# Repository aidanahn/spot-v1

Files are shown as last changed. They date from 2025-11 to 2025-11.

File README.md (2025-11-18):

# spot-v1

## Table of Contents
1. [Description](#description)
2. [Milo](#milo-wip)
3. [Tools](#tools)
4. [Bill of Materials](#bill-of-materials)
5. [Fastener List](#fastener-list)
6. [Printing List](#printing-list)
7. [Printing Orientations](#printing-orientations)
8. [License](#license)

## Description
A fast and reliable 4WD 3D-printable RC car design

Assembly: [Onshape Link](https://cad.onshape.com/documents/7f341d22941a2e14df29ce4a/w/e412618fee4bd938372718a9/e/cd4b9ad8284ddeb69a4dfc13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)

## Milo (WIP)
Track & Field pacer designed to run consistent lap times and help with pacing during training (Uses the same car design from Spot V1).

Check the project out here: (https://github.com/aidanahn/pacer_v3_control)

## Tools
- 3D Printer
- Hacksaw
- Allen Keys
  - 2.0mm
  - 2.5mm
  - 3.0mm

## Bill of Materials
| Quantity | Part Name | Specifications |
| --- | --- | --- |
| 19 | 10x15x4mm Bearing | |
| 4 | 5x10x4mm Bearing | |
| 1 | 8x12x3.5mm Bearing | |
| 2 | 200mm M3 Rod | |
| 4 | M3 Tie Rod End | |
| 1 | 35kg Servo | |
| 1 | Motor | Motor mount built for [QUICRUN Fusion SE (2in1 FOC system)](https://www.hobbywingdirect.com/collections/quicrun-brushless-system/products/quicrun-fusion-se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) |
| 1 | RC Reciever | |
| 1 | ESC | |
| 4 | Wheels | Wheel Hub built for 14mm hex wheels |
| 1 | LiPo Battery | |
| 1 | 20T Timing Pulley | Must have 8mm bore |
| 1 | 40T Timing Pulley | Must have 8mm bore |
| 1 | 120mm Timing Belt | |
| 2 | Differential | The differential case is specifically built to house [this differential](https://www.amazon.com/Mirthobby-Housing-Complete-Volcano-Unassembled/dp/B07YWQ7G9Q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) |
| | PETG Filament | |
| | Grease | |

## Fastener List
| Quantity | Size | Length | Head | Type |
| --- | ---- | --- | ---- | ---- |
| 16 | M3 | 16mm | Socket Head | Screw |
| 18 | M3 | 12mm | Socket Head | Screw |
| 14 | M3 | 12mm | Button Head | Screw |
| 2 | M3 | 20mm | Socket Head | Screw |
| 15 | M3 | 25mm | Socket Head | Screw |
| 8 | M3 | 35mm | Socket Head | Screw |
| 6 | M3 | | | Washer |
| 16 | M3 | 4mm | Socket Head | Screw |
| 13 | M3 | | | Nut |
| 4 | M3 | 8mm | Button Head | Screw |
| 4 | M3 | 16mm | Button Head | Screw |
| 1 | M3 | 30mm | Socket Head | Screw |
| 4 | M4 | 20mm | Socket Head | Screw |
| 4 | M4 | | | Nylon Locknut |

## Printing List
| Quantity | Part Name | Description |
| --- | --- | --- |
| 1 | [Front Chassis](cad/Front_Chassis.step) | Main structural front frame holding servo, steering linkages, and front suspension system|
| 1 | [Rear Chassis](cad/Rear_Chassis.step) | Main structural rear frame holding motor, belt drive, and rear suspension system|
| 1 | [Right Reinforcement Beam](cad/Right_Reinforcement_Beam.step) | Connects front chassis to rear chassis |
| 1 | [Left Reinforcement Beam](cad/Left_Reinforcement_Beam.step) | Connects front chassis to rear chassis |
| 2 | [Lower Differential Case](cad/Lower_Differential_Case.step) | Protective housing for differential |
| 2 | [Upper Differential Case](cad/Upper_Differential_Case.step) | Protective housing for differential |
| 2 | [Upper Control Arm Bracket](cad/Upper_Control_Arm_Bracket.step) | Mounting bracket for the upper control arms to attach to the chassis |
| 4 | [Upper Control Arm](cad/Upper_Control_Arm.step) | Upper suspension arm that connects uprights to the chassis |
| 1 | [Rear Left Lower Control Arm](cad/Rear_Left_Lower_Control_Arm.step) | Lower suspension arm that connects uprights to the chassis |
| 1 | [Rear Right Lower Control Arm](cad/Rear_Right_Lower_Control_Arm.step) | Lower suspension arm that connects uprights to the chassis |
| 1 | [Front Left Lower Control Arm](cad/Front_Left_Lower_Control_Arm.step) | Lower suspension arm that connects uprights to the chassis |
| 1 | [Front Right Lower Control Arm](cad/Front_Right_Lower_Control_Arm.step) | Lower suspension arm that connects uprights to the chassis |
| 1 | [Electronics Bed](cad/Electronics_Bed.step) | Strengthens connection between front and rear chassis and acts as mounting plate for electronics (ESC, receiver, LiPo, etc) |
| 4 | [Differential Drive Cup Adapter](cad/Differential_Drive_Cup_Adapter.step) | Adapter between differential output and drive cup |
| 4 | [Differential Drive Cup](cad/Differential_Drive_Cup.step) | Cup that connects differential output to drive the wheels |
| 2 | [Front Upright](cad/Front_Upright.step) | Front wheel carrier that allows the steering knuckles to pivot and houses the wheel drive cup |
| 2 | [Rear Upright](cad/Rear_Upright.step) | Rear wheel carrier housing the wheel drive cup |
| 2 | [Pinion Carrier](cad/Pinion_Carrier.step) | Holds differential pinion gears in place |
| 1 | [Left Steering Knuckle](cad/Left_Steering_Knuckle.step) | Allows wheels to pivot for steering input |
| 1 | [Right Steering Knuckle](cad/Right_Steering_Knuckle.step) | Allows wheels to pivot for steering input |
| 1 | [Servo Mount](cad/Servo_Mount.step) | Holds servo securely in place |
| 1 | [Servo Steering Linkage](cad/Servo_Steering_Linkage.step) | Transmits servo power to the steering bar |
| 1 | [Steering Bar](cad/Steering_Bar.step) | Main steering bar linking left and right wheels |
| 1 | [Steering Linkage](cad/Steering_Linkage.step) | Follows the same motion as the steering linkage to keep the steering bar in place |
| 4 | [Wheel Drive Cup](cad/Wheel_Drive_Cup.step) | Connects wheel hubs to the differential output cups |
| 4 | [Wheel Hub](cad/Wheel_Hub.step) | Mounting point for wheels |
| 1 | [Steering Mount](cad/Steering_Mount.step) | Allows the steering linkage to pivot around its axis |
| 4 | [Dogbone](cad/Dogbone.step) | Transfers power directly from the differential drive cup to the wheel drive cup |
| 1 | [Front Gearbox Cover](cad/Front_Gearbox_Cover.step) | Covers the frontside of the belt drive system |
| 1 | [Rear Gearbox Cover](cad/Rear_Gearbox_Cover.step) | Covers the rearside of the belt drive system |
| 1 | [Front Gearbox Cup](cad/Front_Gearbox_Cup.step) | Outputs power to the front differential set |
| 1 | [Rear Gearbox Cup](cad/Rear_Gearbox_Cup.step) | Outputs power to the rear differential set |
| 1 | [Shaft Coupling](cad/Shaft_Coupling.step) | Mounts onto motor shaft to transfer power to timing pulleys |

## Printing Orientations
### Front Chassis
**Recommended Print Settings:**
- **Layer Height:** 0.2mm
- **Infill:** 15% (Gyroid)
- **Supports:** Yes (Manual)
- **Material:** PETG
- **Brim:** Outer brim only

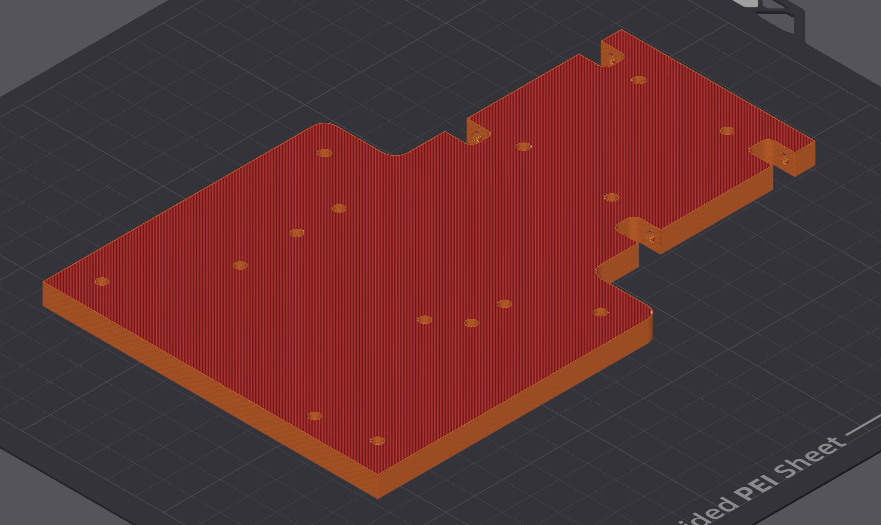
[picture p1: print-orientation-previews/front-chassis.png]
Front Chassis


### Rear Chassis
**Recommended Print Settings:**
- **Layer Height:** 0.2mm
- **Infill:** 15% (Gyroid)
- **Supports:** Yes (Manual)
- **Material:** PETG
- **Brim:** Outer brim only

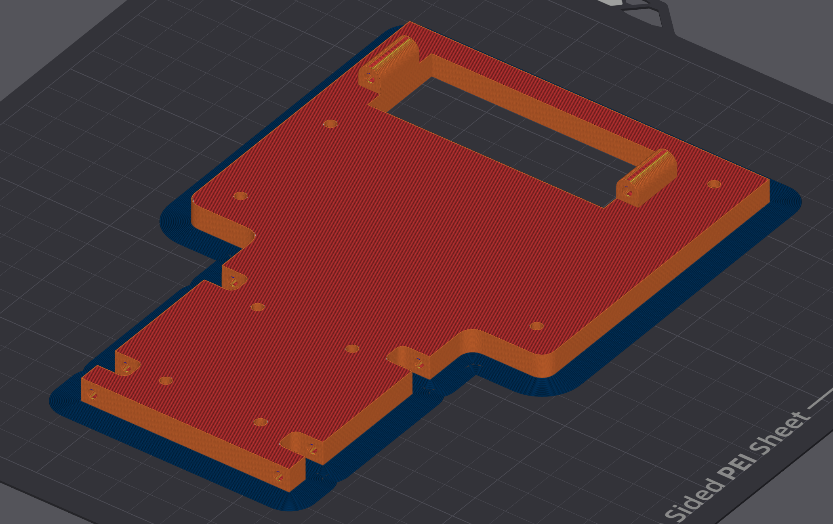
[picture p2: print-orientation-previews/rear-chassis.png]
Rear Chassis


### Right Reinforcement Beam
**Recommended Print Settings:**
- **Layer Height:** 0.2mm
- **Infill:** 15% (Gyroid)
- **Supports:** No
- **Material:** PETG
- **Brim:** Outer brim only

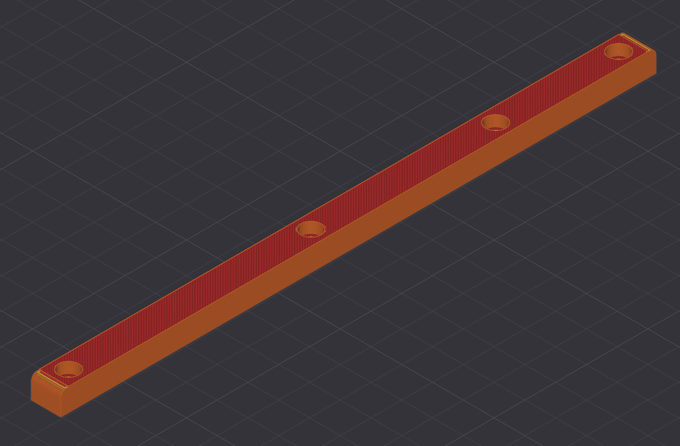
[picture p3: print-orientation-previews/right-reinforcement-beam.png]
Right Reinforcement Beam


### Left Reinforcement Beam
**Recommended Print Settings:**
- **Layer Height:** 0.2mm
- **Infill:** 15% (Gyroid)
- **Supports:** No
- **Material:** PETG
- **Brim:** Outer brim only

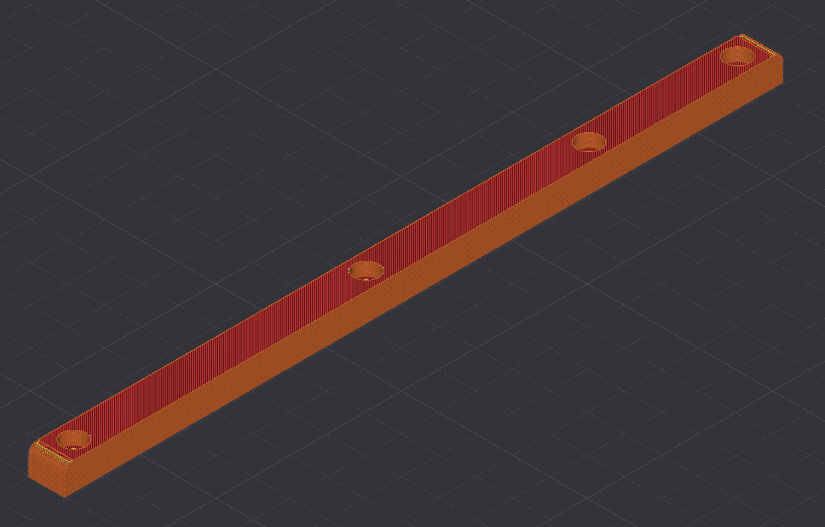
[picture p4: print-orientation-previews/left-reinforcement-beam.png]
Left Reinforcement Beam


### Lower Differential Case
**Recommended Print Settings:**
- **Layer Height:** 0.2mm
- **Infill:** 15% (Gyroid)
- **Supports:** Yes (Manual)
- **Material:** PETG
- **Brim:** Outer brim only

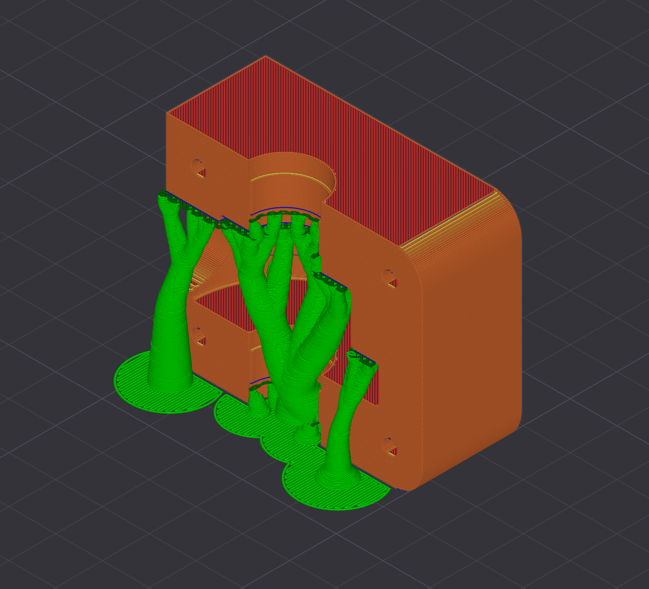
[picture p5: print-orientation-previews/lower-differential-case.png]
Lower Differential Case


### Upper Differential Case
**Recommended Print Settings:**
- **Layer Height:** 0.2mm
- **Infill:** 15% (Gyroid)
- **Supports:** Yes (Manual)
- **Material:** PETG
- **Brim:** Outer brim only

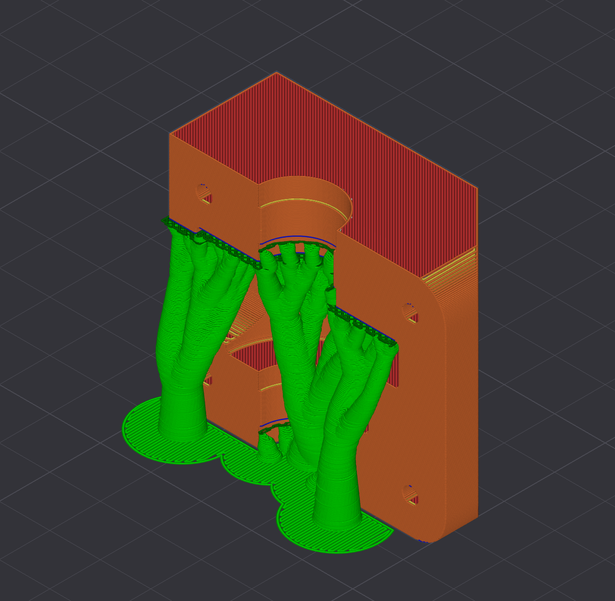
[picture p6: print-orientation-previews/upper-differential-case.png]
Upper Differential Case


### Upper Control Arm Bracket
**Recommended Print Settings:**
- **Layer Height:** 0.2mm
- **Infill:** 15% (Gyroid)
- **Supports:** No
- **Material:** PETG
- **Brim:** Outer brim only

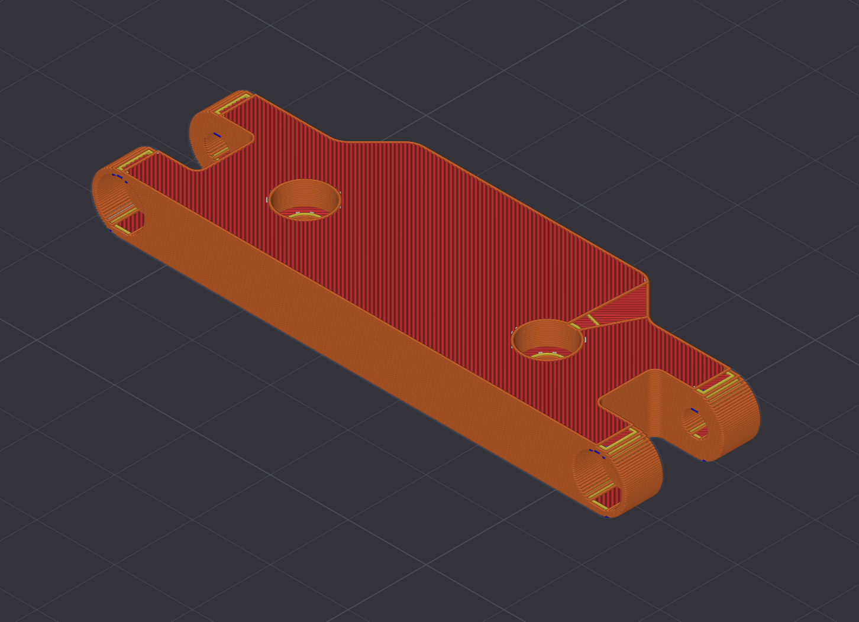
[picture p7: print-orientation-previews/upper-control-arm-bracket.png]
Upper Control Arm Bracket


### Upper Control Arm
**Recommended Print Settings:**
- **Layer Height:** 0.2mm
- **Infill:** 30% (Gyroid)
- **Supports:** No
- **Material:** PETG
- **Brim:** Outer brim only

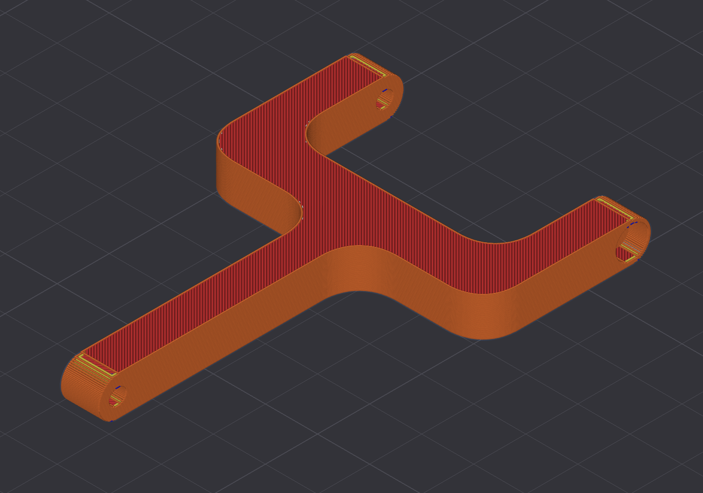
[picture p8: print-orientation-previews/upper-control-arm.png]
Upper Control Arm


### Lower Control Arm
**Recommended Print Settings:**
- **Layer Height:** 0.2mm
- **Infill:** 30% (Gyroid)
- **Supports:** No
- **Material:** PETG
- **Brim:** Outer brim only

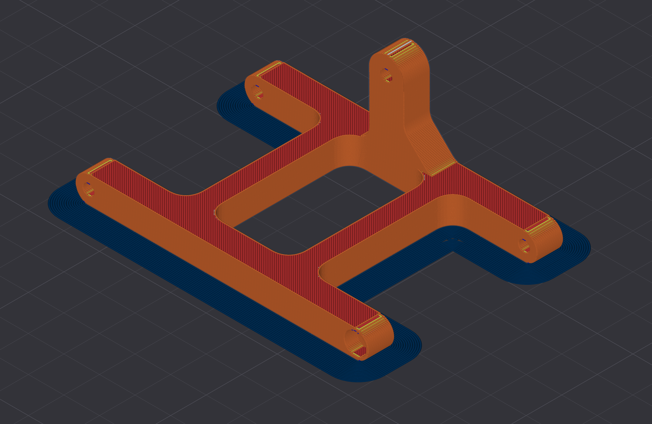
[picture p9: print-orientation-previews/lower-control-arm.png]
Lower Control Arm


### Electronics Bed
**Recommended Print Settings:**
- **Layer Height:** 0.2mm
- **Infill:** 15% (Gyroid)
- **Supports:** Yes (Automatic)
- **Material:** PETG
- **Brim:** Outer brim only

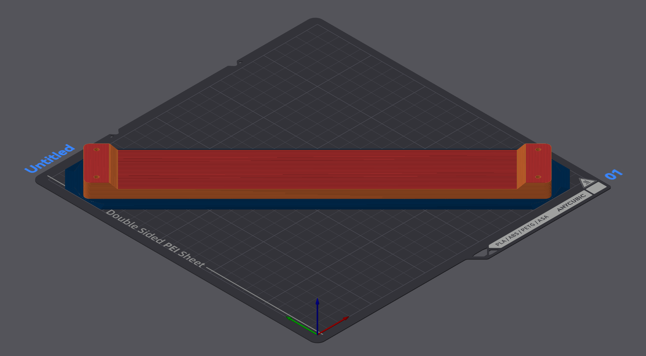
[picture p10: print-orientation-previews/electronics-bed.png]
Electronics Bed


### Differential Drive Cup Adapter
**Recommended Print Settings:**
- **Layer Height:** 0.1mm
- **Infill:** 30% (Gyroid)
- **Supports:** Yes (Automatic)
- **Material:** PETG

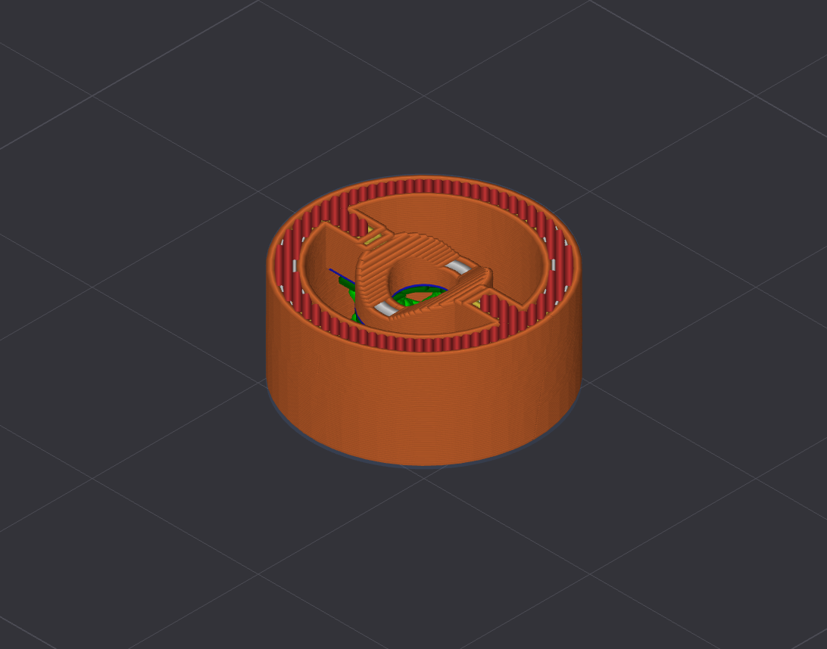
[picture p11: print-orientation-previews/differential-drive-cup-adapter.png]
Differential Drive Cup Adapter


### Differential Drive Cup
**Recommended Print Settings:**
- **Layer Height:** 0.1mm
- **Infill:** 30% (Gyroid)
- **Supports:** Yes (Automatic)
- **Material:** PETG

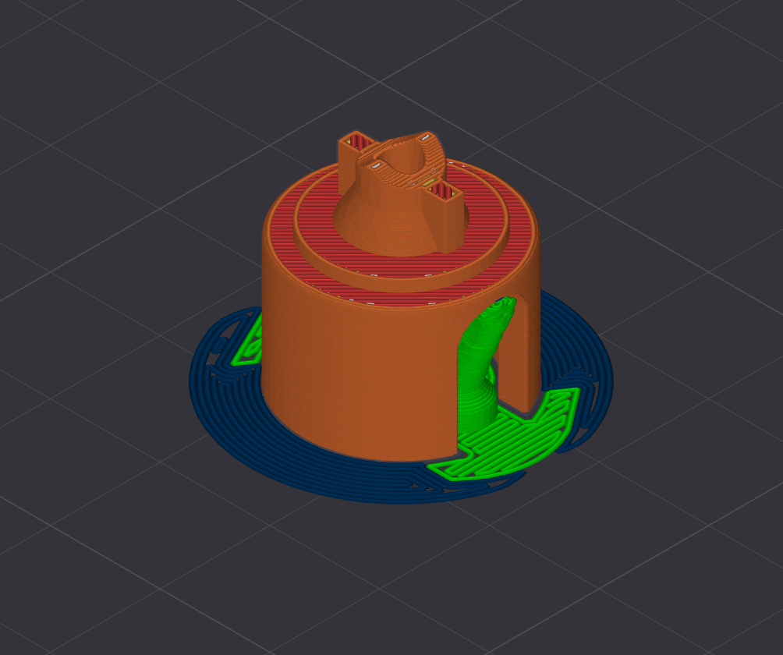
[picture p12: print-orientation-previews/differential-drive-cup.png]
Differential Drive Cup


### Front Upright
**Recommended Print Settings:**
- **Layer Height:** 0.2mm
- **Infill:** 30% (Gyroid)
- **Supports:** Yes (Manual)
- **Material:** PETG

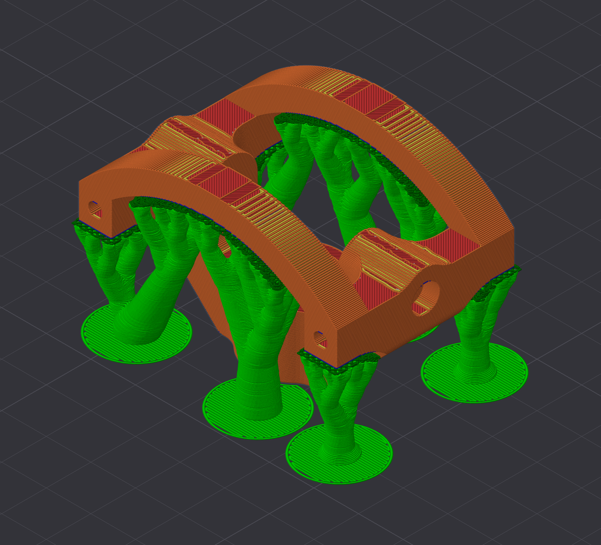
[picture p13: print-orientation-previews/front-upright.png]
Front Upright


### Rear Upright
**Recommended Print Settings:**
- **Layer Height:** 0.2mm
- **Infill:** 30% (Gyroid)
- **Supports:** Yes (Manual)
- **Material:** PETG

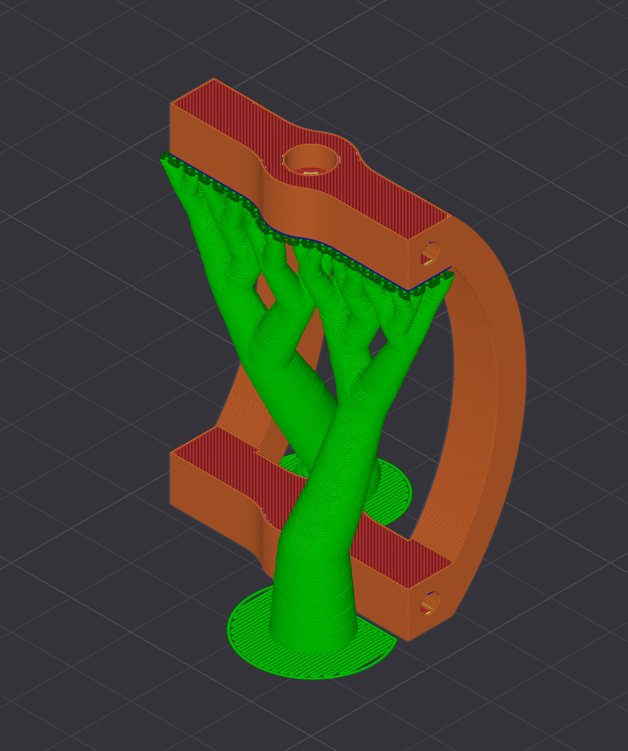
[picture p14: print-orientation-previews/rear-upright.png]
Rear Upright


### Pinion Carrier
**Recommended Print Settings:**
- **Layer Height:** 0.2mm
- **Infill:** 15% (Gyroid)
- **Supports:** No
- **Material:** PETG
- **Brim:** Outer brim only

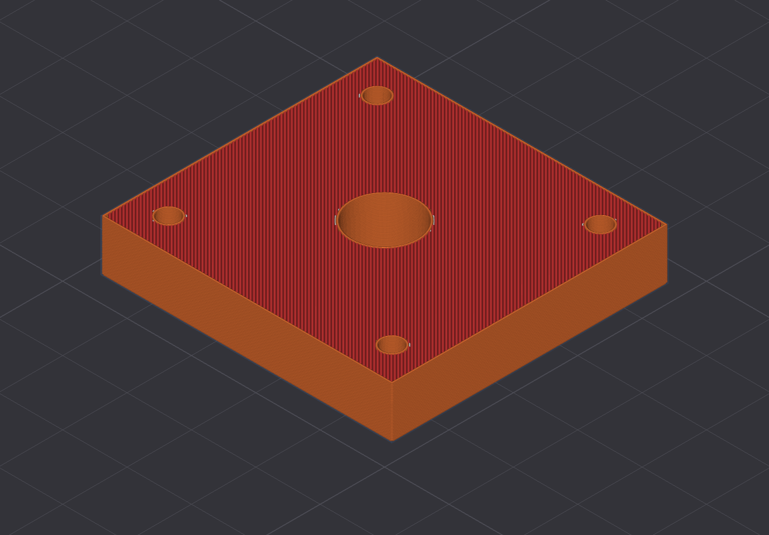
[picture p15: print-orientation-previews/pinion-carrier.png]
Pinion Carrier


### Steering Knuckle
**Recommended Print Settings:**
- **Layer Height:** 0.2mm
- **Infill:** 30% (Gyroid)
- **Supports:** Yes (Manual)
- **Material:** PETG

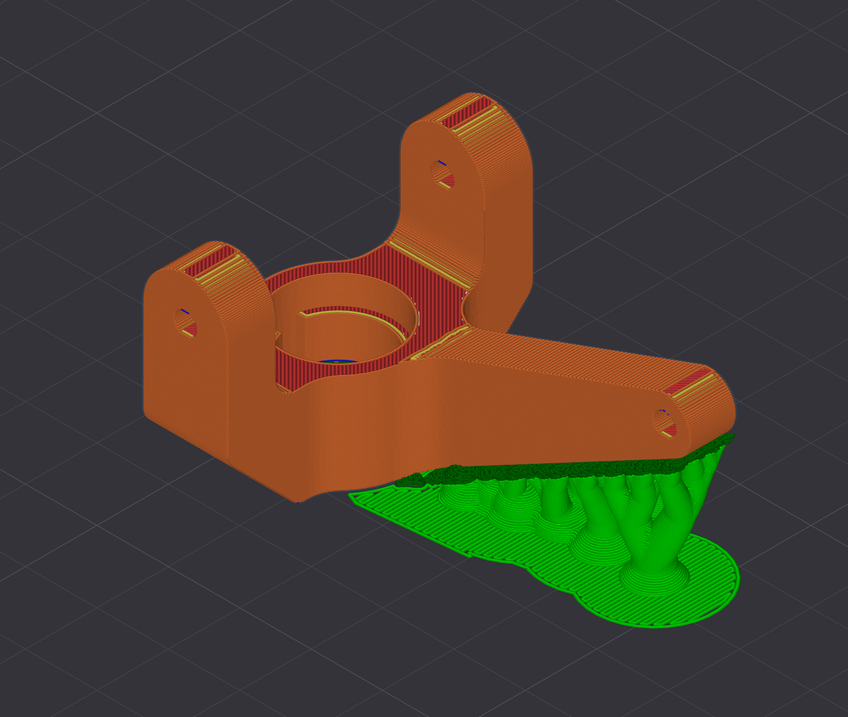
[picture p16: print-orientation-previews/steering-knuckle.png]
Steering Knuckle


### Servo Mount
**Recommended Print Settings:**
- **Layer Height:** 0.2mm
- **Infill:** 30% (Gyroid)
- **Supports:** Yes (Manual)
- **Material:** PETG

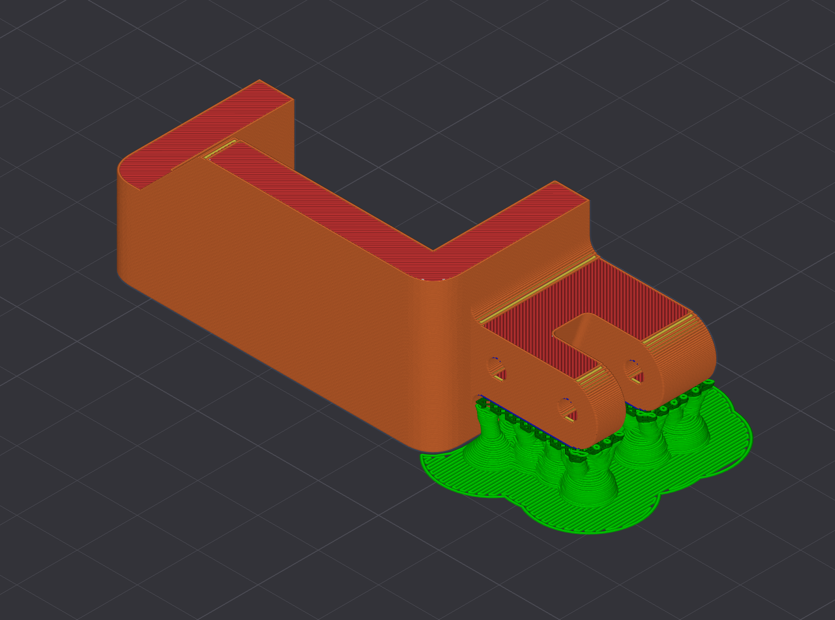
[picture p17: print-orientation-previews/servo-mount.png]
Servo Mount


### Servo Steering Linkage
**Recommended Print Settings:**
- **Layer Height:** 0.2mm
- **Infill:** 30% (Gyroid)
- **Supports:** No
- **Material:** PETG

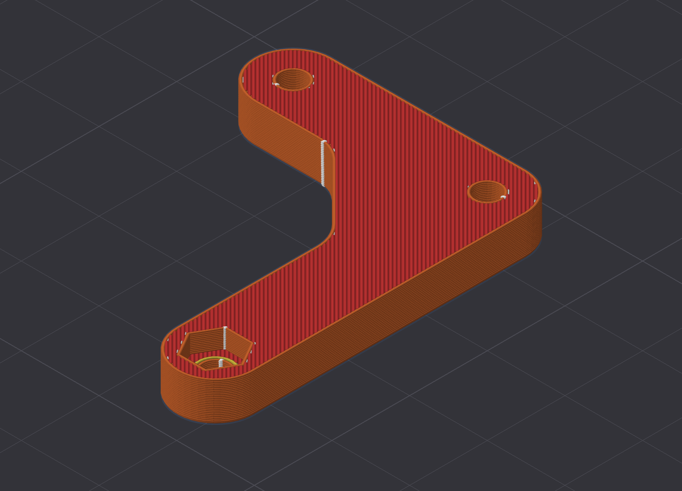
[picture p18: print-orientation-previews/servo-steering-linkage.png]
Servo Steering Linkage


### Steering Bar
**Recommended Print Settings:**
- **Layer Height:** 0.2mm
- **Infill:** 30% (Gyroid)
- **Supports:** No
- **Material:** PETG

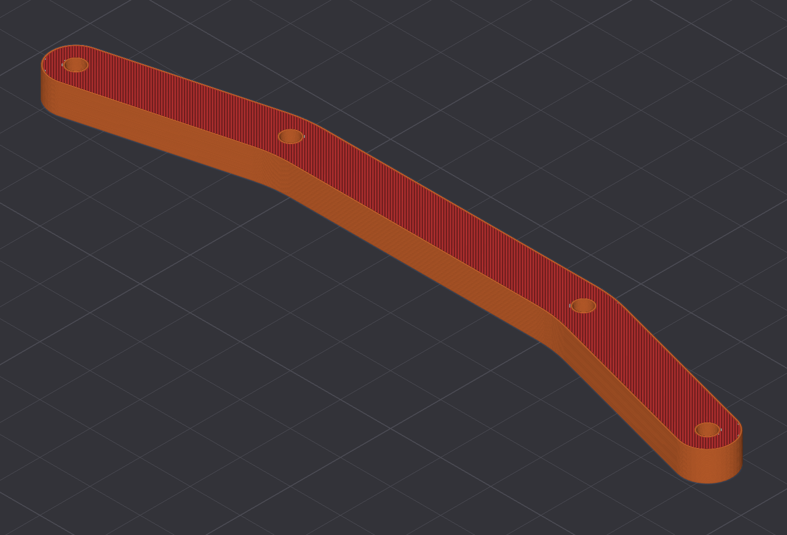
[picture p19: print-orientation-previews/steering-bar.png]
Steering Bar


### Steering Linkage
**Recommended Print Settings:**
- **Layer Height:** 0.2mm
- **Infill:** 30% (Gyroid)
- **Supports:** No
- **Material:** PETG

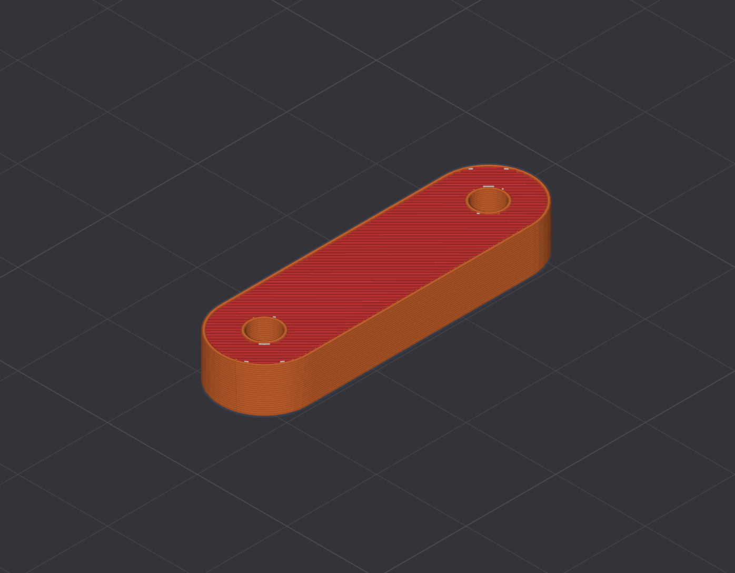
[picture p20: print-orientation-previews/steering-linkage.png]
Steering Linkage


### Wheel Drive Cup
**Recommended Print Settings:**
- **Layer Height:** 0.2mm
- **Infill:** 30% (Gyroid)
- **Supports:** Yes (Automatic)
- **Material:** PETG

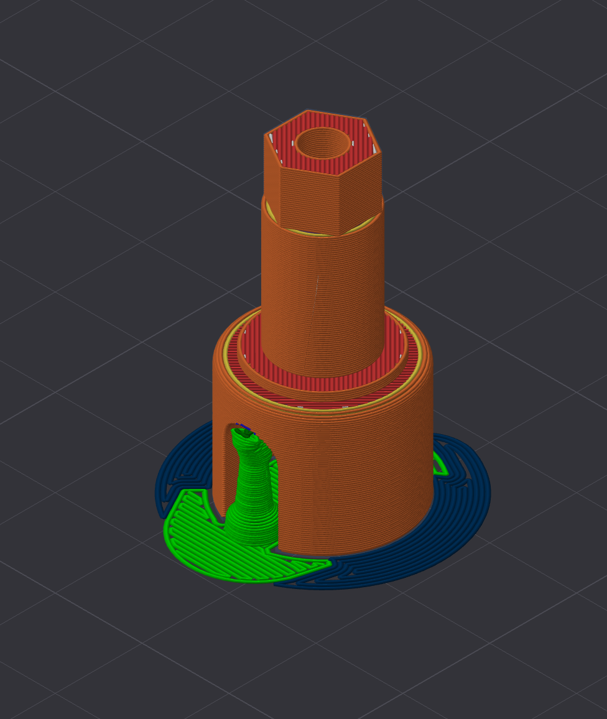
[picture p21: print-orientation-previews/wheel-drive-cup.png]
Wheel Drive Cup


### Wheel Hub
**Recommended Print Settings:**
- **Layer Height:** 0.2mm
- **Infill:** 30% (Gyroid)
- **Supports:** No
- **Material:** PETG

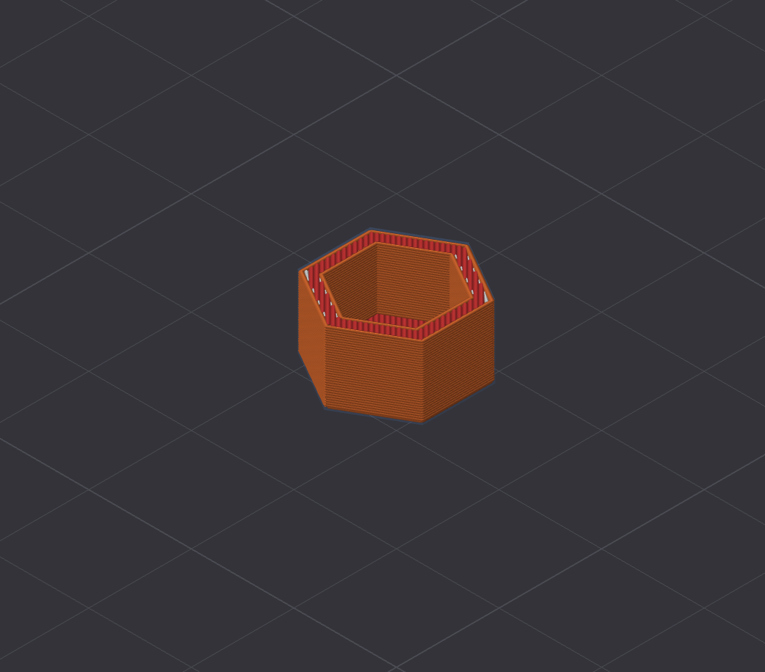
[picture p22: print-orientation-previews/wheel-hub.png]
Wheel Hub


### Steering Mount
**Recommended Print Settings:**
- **Layer Height:** 0.2mm
- **Infill:** 30% (Gyroid)
- **Supports:** No
- **Material:** PETG

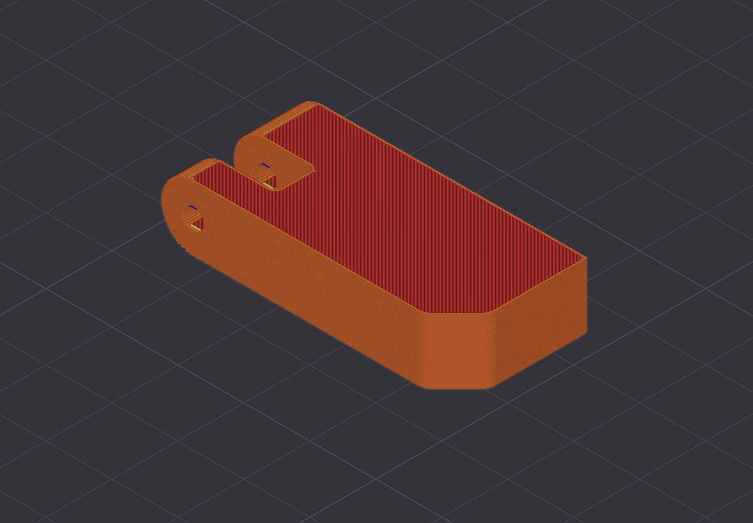
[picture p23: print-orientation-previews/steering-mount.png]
Steering Mount


### Dogbone
**Recommended Print Settings:**
- **Layer Height:** 0.1mm
- **Infill:** 30% (Gyroid)
- **Supports:** Yes (Automatic)
- **Material:** PETG

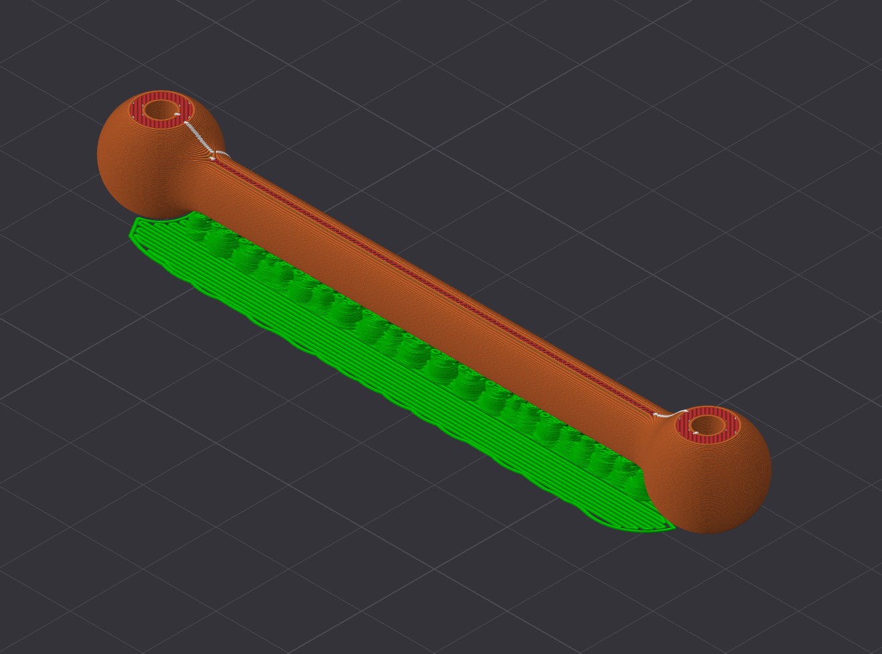
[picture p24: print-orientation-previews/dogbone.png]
Dogbone


### Front Gearbox Cover
**Recommended Print Settings:**
- **Layer Height:** 0.2mm
- **Infill:** 30% (Gyroid)
- **Supports:** Yes (Automatic)
- **Material:** PETG

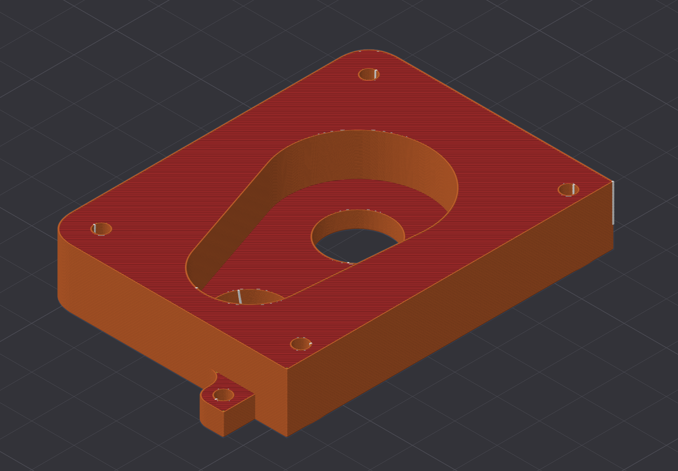
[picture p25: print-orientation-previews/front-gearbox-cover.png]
Front Gearbox Cover


### Rear Gearbox Cover
**Recommended Print Settings:**
- **Layer Height:** 0.2mm
- **Infill:** 30% (Gyroid)
- **Supports:** No
- **Material:** PETG

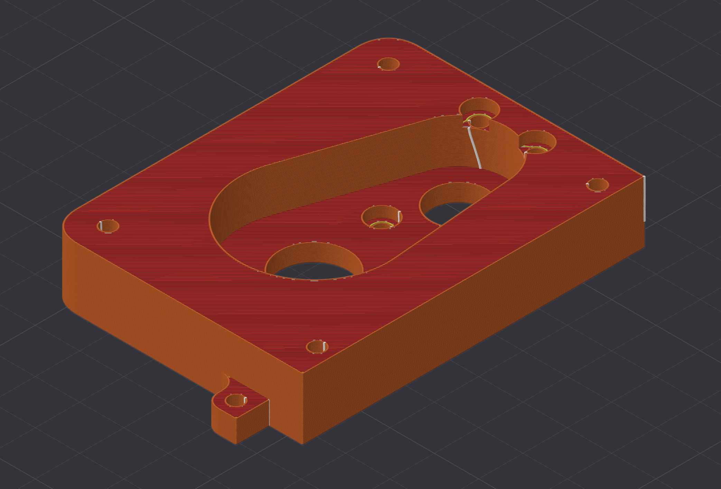
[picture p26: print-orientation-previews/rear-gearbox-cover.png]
Rear Gearbox Cover


### Front Gearbox Cup
**Recommended Print Settings:**
- **Layer Height:** 0.2mm
- **Infill:** 30% (Gyroid)
- **Supports:** Yes (Automatic)
- **Material:** PETG

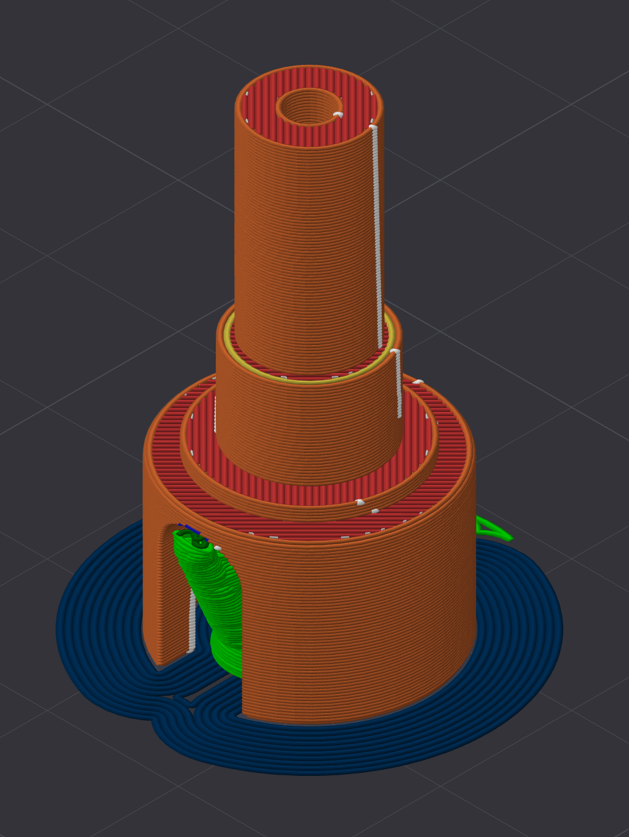
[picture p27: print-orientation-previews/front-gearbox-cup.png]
Front Gearbox Cup


### Rear Gearbox Cup
**Recommended Print Settings:**
- **Layer Height:** 0.2mm
- **Infill:** 30% (Gyroid)
- **Supports:** Yes (Automatic)
- **Material:** PETG

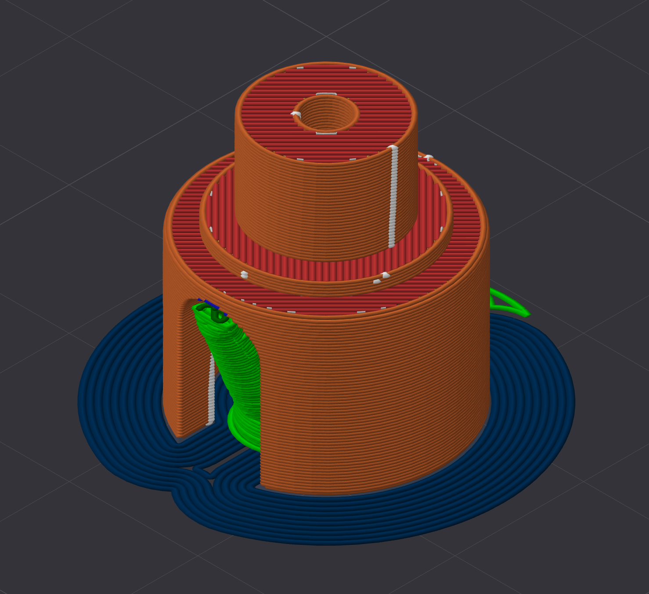
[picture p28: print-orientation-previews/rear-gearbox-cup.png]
Rear Gearbox Cup


### Shaft Coupling
**Recommended Print Settings:**
- **Layer Height:** 0.1mm
- **Infill:** 30% (Gyroid)
- **Supports:** Yes (Automatic)
- **Material:** PETG

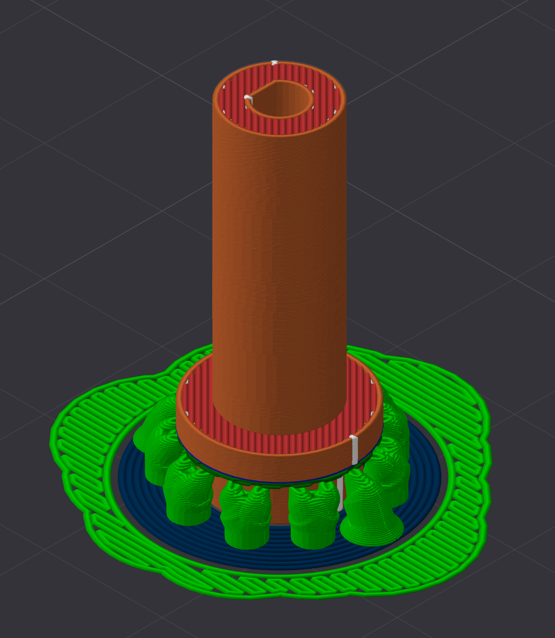
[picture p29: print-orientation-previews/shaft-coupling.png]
Shaft Coupling


## License
This work is licensed under a [MIT License](LICENSE).

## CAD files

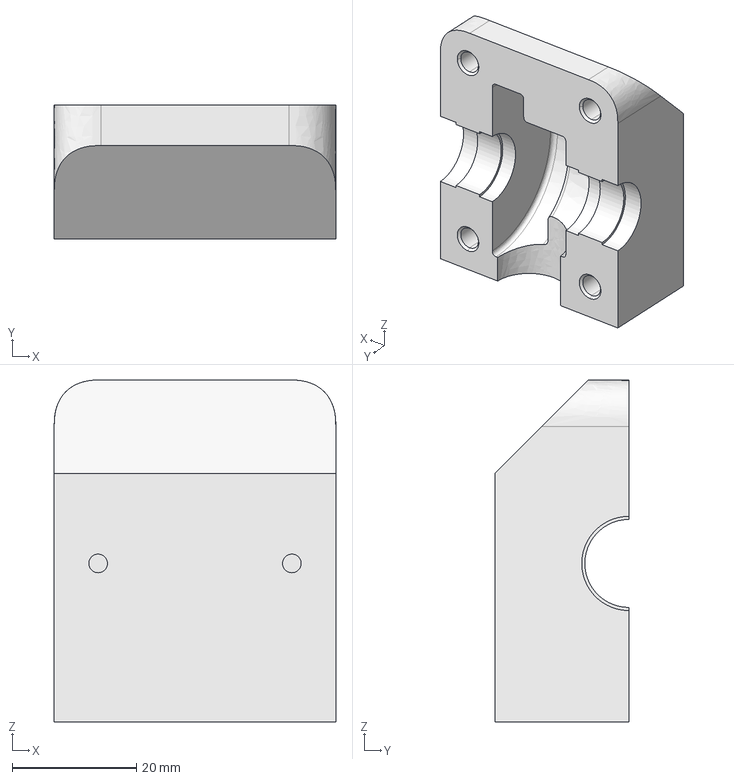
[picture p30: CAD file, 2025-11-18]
cad/Upper_Differential_Case.step
45.3 x 21.5 x 55.0 mm

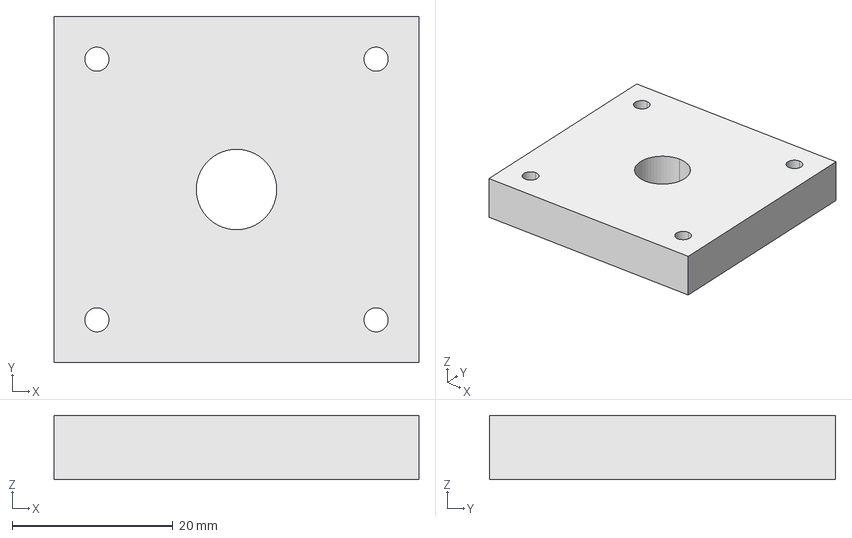
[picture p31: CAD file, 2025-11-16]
cad/Pinion_Carrier.step
45.3 x 43.0 x 8.00 mm

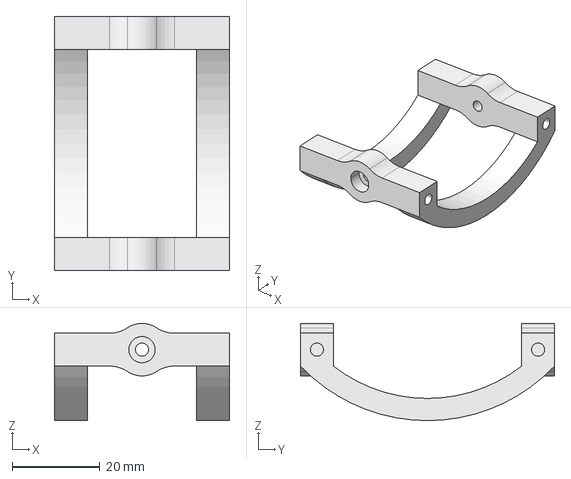
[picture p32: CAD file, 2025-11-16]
cad/Front_Upright.step
40.0 x 58.0 x 22.2 mm

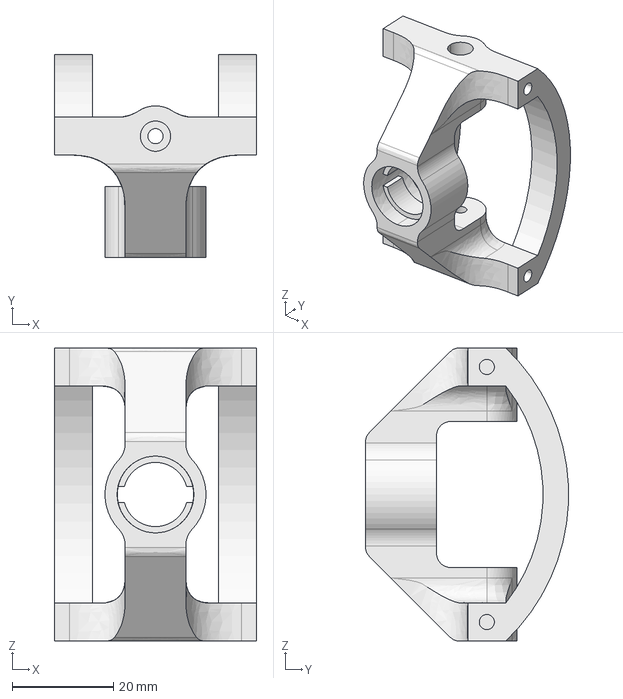
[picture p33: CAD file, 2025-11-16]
cad/Rear_Upright.step
40.0 x 40.2 x 58.0 mm

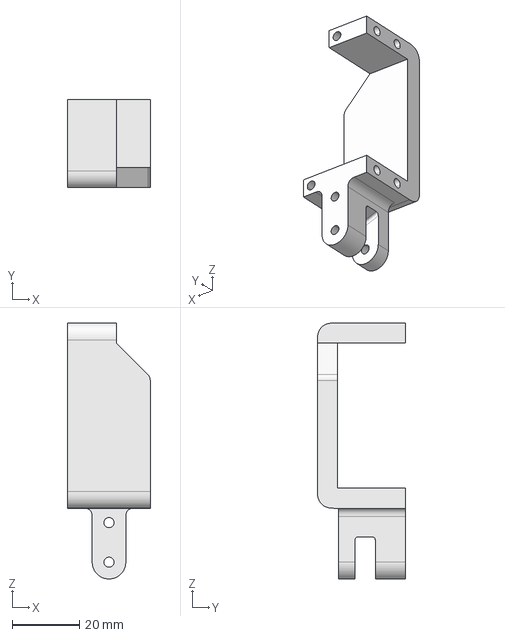
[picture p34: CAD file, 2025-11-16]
cad/Servo_Mount.step
24.5 x 26.2 x 76.0 mm

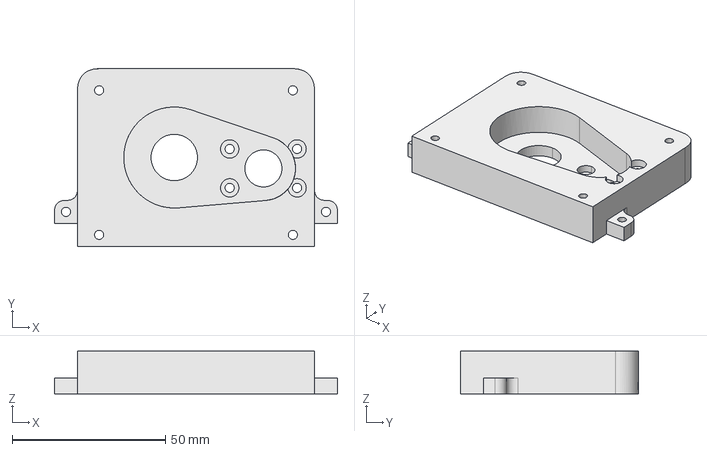
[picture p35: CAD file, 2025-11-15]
cad/Rear_Gearbox_Cover.step
92.4 x 58.0 x 14.0 mm

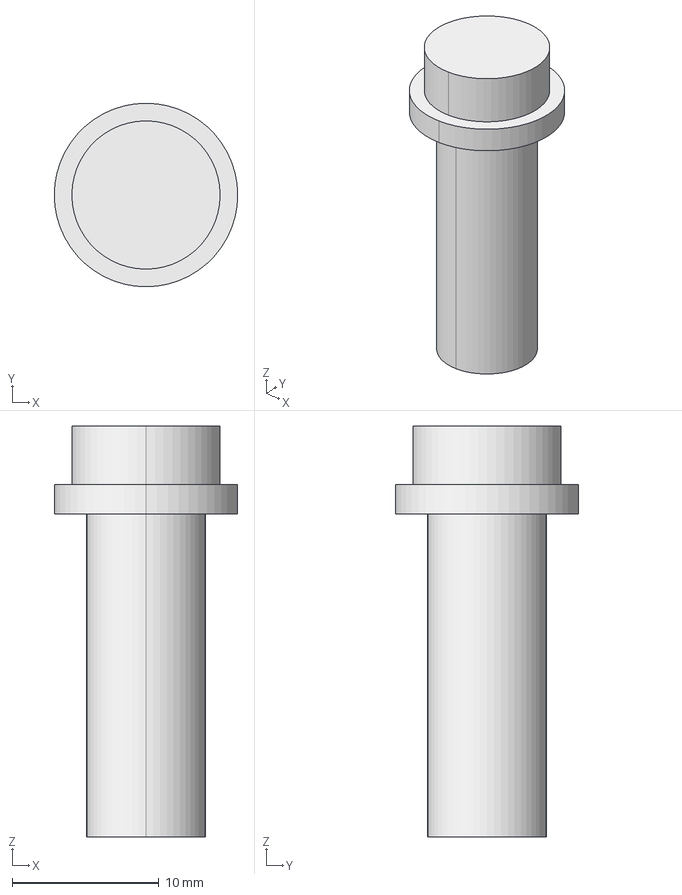
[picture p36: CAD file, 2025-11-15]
cad/Shaft_Coupling.step
12.5 x 12.5 x 28.0 mm

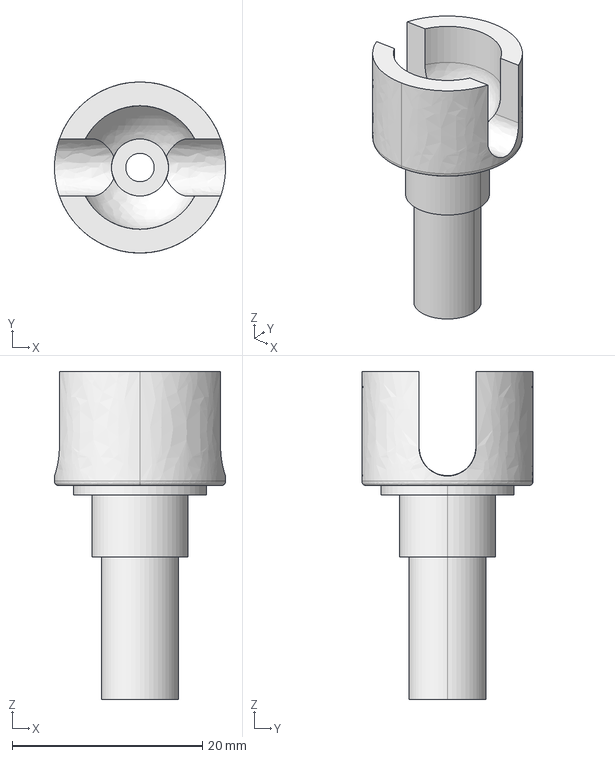
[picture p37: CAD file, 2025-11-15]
cad/Front_Gearbox_Cup.step
18.0 x 18.0 x 34.5 mm

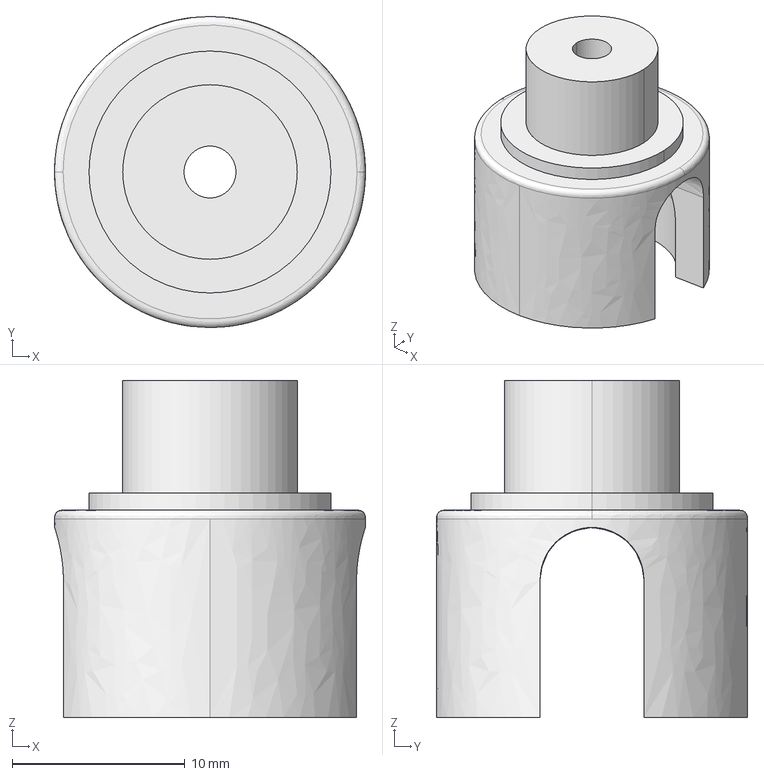
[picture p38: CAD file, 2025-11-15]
cad/Rear_Gearbox_Cup.step
18.0 x 18.0 x 19.5 mm

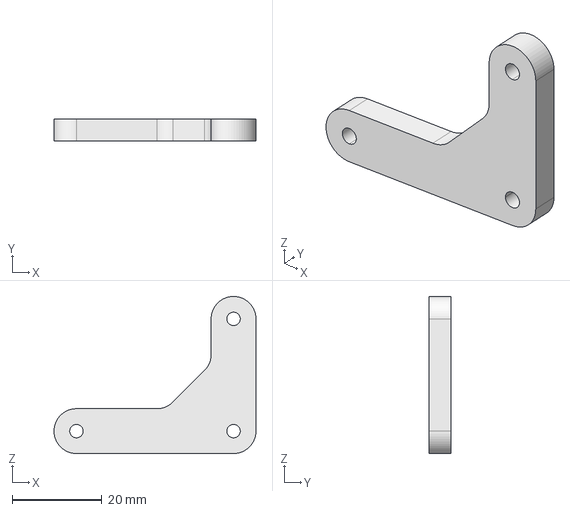
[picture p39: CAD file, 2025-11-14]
cad/Servo_Steering_Linkage.step
45.0 x 5.00 x 35.0 mm

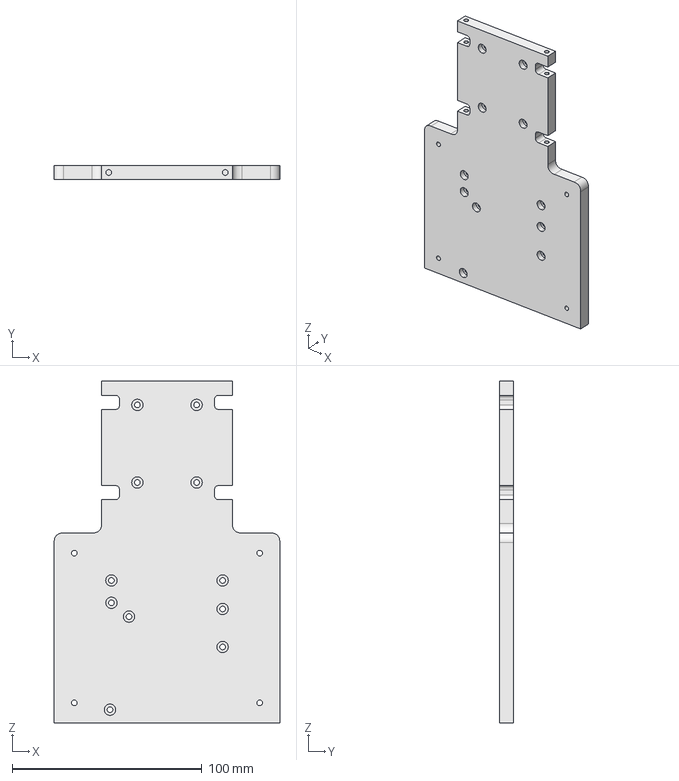
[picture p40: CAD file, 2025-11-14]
cad/Front_Chassis.step
118.8 x 7.50 x 180.0 mm

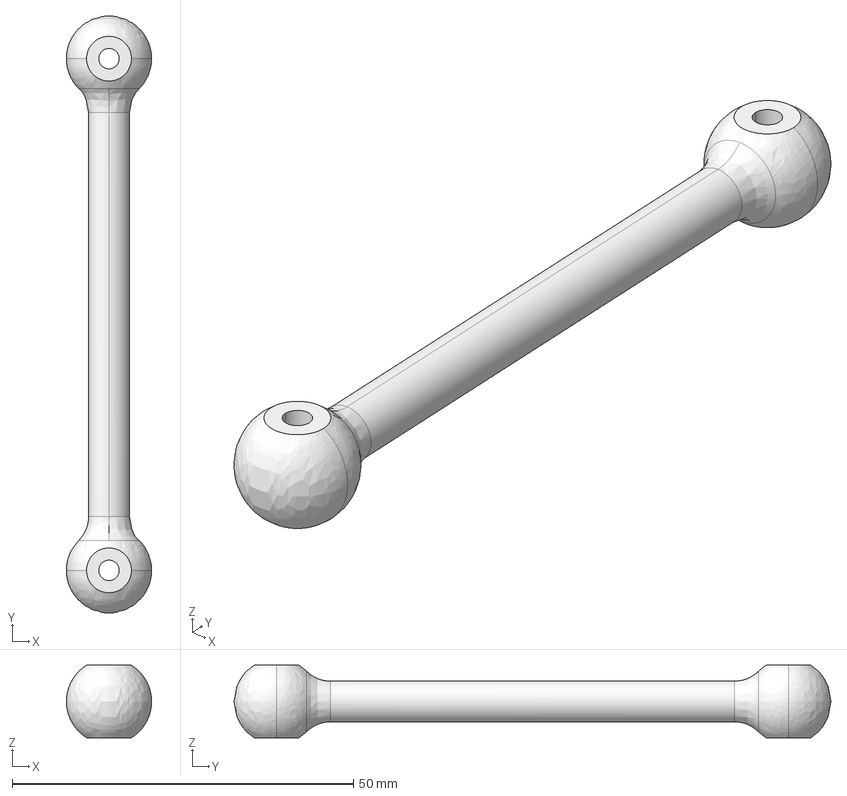
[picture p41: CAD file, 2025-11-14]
cad/Dogbone.step
12.5 x 87.5 x 10.6 mm

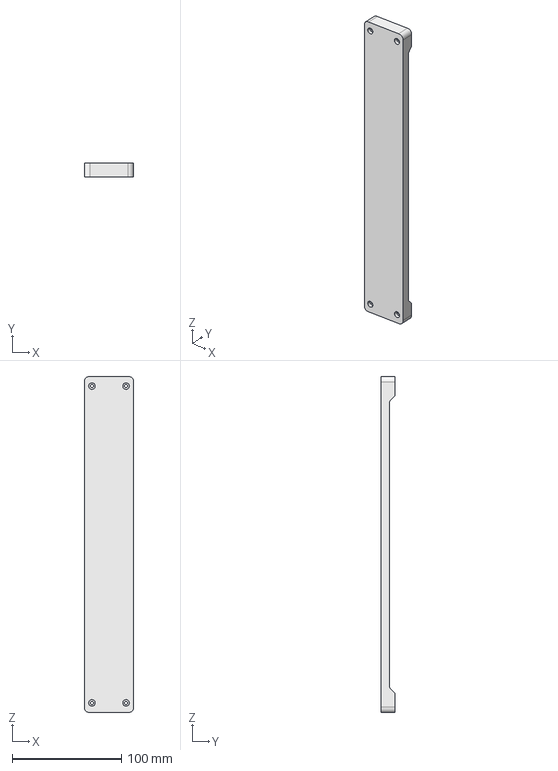
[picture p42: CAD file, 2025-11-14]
cad/Electronics_Bed.step
45.0 x 13.0 x 307.5 mm

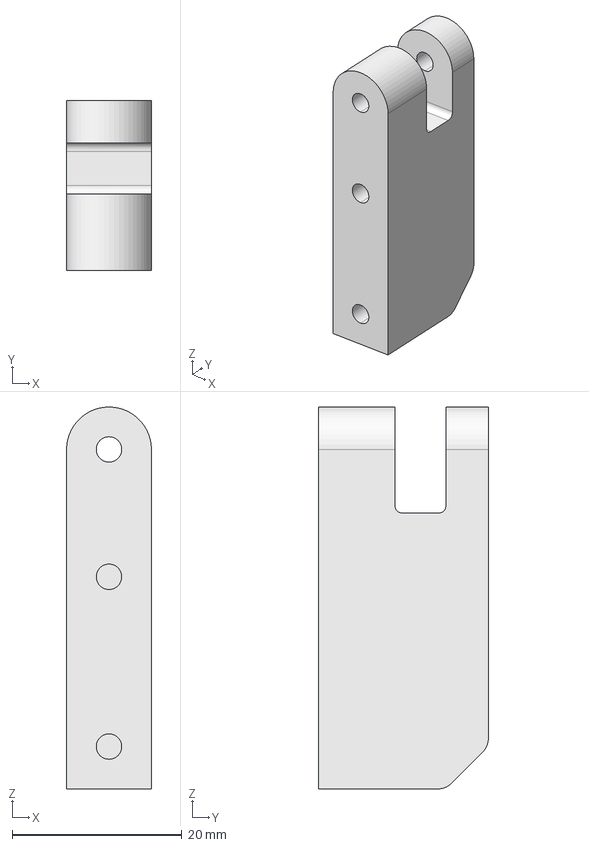
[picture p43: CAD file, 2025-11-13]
cad/Steering_Mount.step
10.0 x 20.0 x 45.0 mm

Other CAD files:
cad/Lower_Differential_Case.step
cad/Front_Gearbox_Cover.step
cad/Steering_Bar.step
cad/Steering_Linkage.step
cad/Differential_Drive_Cup.step
cad/Differential_Drive_Cup_Adapter.step
cad/Front_Belt_Cup.step
cad/Front_Belt_Housing.step
cad/Front_Driveshaft.step
cad/Front_Left_Lower_Control_Arm.step
cad/Front_Right_Lower_Control_Arm.step
cad/Left_Reinforcement_Beam.step
cad/Left_Steering_Knuckle.step
cad/Motor_Shaft_Adapter.step
cad/Rear_Belt_Cup.step
cad/Rear_Belt_Housing.step
cad/Rear_Chassis.step
cad/Rear_Driveshaft.step
cad/Rear_Left_Lower_Control_Arm.step
cad/Rear_Right_Lower_Control_Arm.step
cad/Right_Reinforcement_Beam.step
cad/Right_Steering_Knuckle.step
cad/Upper_Control_Arm.step
cad/Upper_Control_Arm_Bracket.step
cad/Wheel_Drive_Cup.step
cad/Wheel_Hub.step

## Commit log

2025-11-13 Added all individual parts
    [Differential_Drive_Cup.step, Differential_Drive_Cup_Adapter.step, Front_Belt_Cup.step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]
2025-11-13 Added steering parts
    [Servo_Mount.step, Servo_Steering_Linkage.step, Steering_Bar.step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]
2025-11-13 Update README with Printing List section
    Added a new section for Printing List with details.
2025-11-13 Enhance part descriptions in README
    Updated descriptions for various parts in the printing list to provide detailed information about each component.
2025-11-13 Add link to Front Chassis in README
2025-11-14 Update parts list with links to CAD files
2025-11-14 Update lower control arm and steering knuckle entries
2025-11-14 Add Bill of Materials section to README
2025-11-14 Enhance BOM with specific product details and links
    Added specific product links and details to the Bill of Materials (BOM) section in README.md.
2025-11-14 Update Bill of Materials in README.md
2025-11-14 Fix formatting in Bill of Materials section
2025-11-14 Update printing list with new components
    Added new components to the printing list including Tie Rod, Motor, Timing Pulleys, and Timing Belt with their respective links.
2025-11-14 Update README with parts substitution note
    Added a note about parts substitution in the BOM section.
2025-11-14 Added print orientation preivews
    [Electronics_Bed.step, Motor_Shaft_Adapter.step]
2025-11-14 Added print orientation previews
2025-11-14 Insert front chassis orientation image
    Added image for front chassis orientation in README.
2025-11-14 Revise README structure and remove BOM section
    Updated the README to include links in the Table of Contents and removed the Bill of Materials section.
2025-11-14 Add Steering Mount to CAD components list
2025-11-14 Remove belt drive components and update images
    Removed several components related to the belt drive system from the parts list and updated image references for printing orientations.
2025-11-14 Update README with Front Chassis print settings
    Added recommended print settings for Front Chassis.
2025-11-14 Fix HTML encoding for material in README
2025-11-14 Update README with print settings for new components
    Added print settings and images for various components including Rear Chassis, Reinforcement Beams, and Differential Cases.
2025-11-14 Updated upper differential case design
    [Upper_Differential_Case.step]
2025-11-14 Added dogbone part
    [Dogbone.step]
2025-11-14 Update README with Dogbone specifications
    Added Dogbone component details and print settings.
2025-11-14 Updated dogbone and servo steering linkage images
2025-11-14 Update image in README from steering mount to dogbone
2025-11-14 Updated upper diff case design
    [Upper_Differential_Case.step]
2025-11-14 Updated screw hole depth
    [Front_Chassis.step]
2025-11-14 Updated servo steering linkage
    [Servo_Steering_Linkage.step]
2025-11-14 Revise README with updated links and sections
    Updated the table of contents and modified the assembly link.
2025-11-15 Added new gearbox cad
    [Front_Gearbox_Cover.step, Front_Gearbox_Cup.step, Rear_Gearbox_Cover.step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]
2025-11-15 Updated rear gearbox and added shaft coupling
    [Rear_Gearbox_Cover.step, Shaft_Coupling.step]
2025-11-15 Revise fastener quantities and fix typos
    Updated quantities and corrected spelling in the fastener and printing lists.
2025-11-15 Added gearbox orientation previews
2025-11-15 Update README with print settings for gearbox parts
    Added recommended print settings and images for various gearbox components.
2025-11-16 Revise print settings for Electronics Bed
    Updated recommended print settings for Electronics Bed.
2025-11-16 Edited differential models
    [Front_Upright.step, Lower_Differential_Case.step, Pinion_Carrier.step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]
2025-11-16 Modify print settings for Upper Control Arm Bracket
    Updated infill percentage and added brim recommendation.
2025-11-17 Adjust print settings for reinforcement beams
    Updated infill percentage and added brim settings for reinforcement beams.
2025-11-17 Change infill setting for Rear Chassis to 15%
    Updated infill percentage from 30% to 15% for the Rear Chassis section in the README.
2025-11-18 Updated fastener sizings for upper differential case
    [Upper_Differential_Case.step]
